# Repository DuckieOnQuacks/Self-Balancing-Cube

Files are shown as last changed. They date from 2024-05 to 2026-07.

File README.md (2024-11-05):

# Self-Balancing-Cube

**UPDATE (2024-07-14)**

New code is in **esp32_cube_enc** folder. I changed sensor orientation. So, if you make my cube before, to use this code, you need to reprint one part.

Or you can print redesigned cube https://www.thingiverse.com/thing:6695891

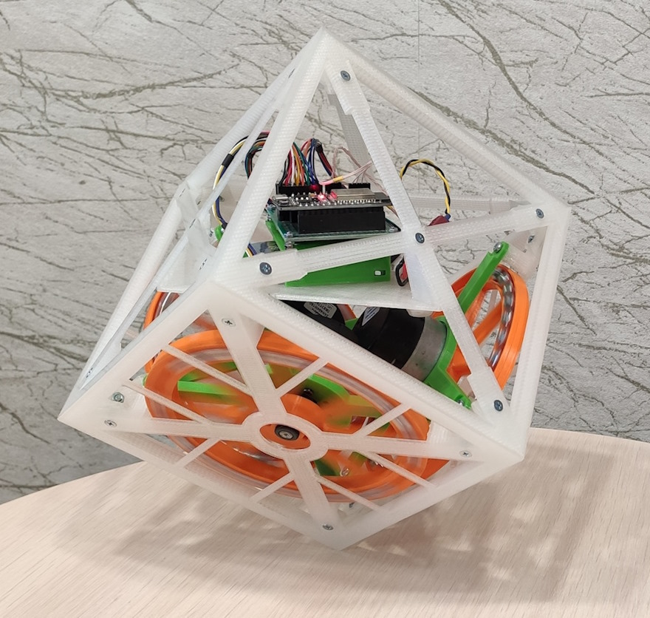
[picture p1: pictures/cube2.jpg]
Cubli


The red connections you see in the schematic must be connected!

If something doesn't work, try the motors test sketch. It tests all motors, rotation directions and encoders.

Folow this video https://youtu.be/ZU0oTBRDgOE

---

ESP32, MPU6050, Nidec 24H brushless motors, 500 mAh LiPo battery.

Balancing controllers can be tuned remotely over bluetooth.

Example:

Send p+ (or p+p+p+p+p+p+p+) for increase K1.

Send p- (or p-p-p-p-p-p-p-) for decrease K1.

The same for K2, K3. Send "i", "s".

Self-Balancing-Cube

Self-Balancing-Cube-Schematic

About schematic:

Battery: 3S1P LiPo (11.1V). 
Buzzer: any 5V active buzzer.
Voltage regulator: any 5V regulator (7805).
All red connections not nescesary for this project! But if you are designing a PCB I recommend making these connections. Maybe I use encoders in the future, you will be able to use the new firmware without any changes.
 
How to build:

https://youtu.be/AJQZFHJzwt4

If something doesn't work, try the motors test sketch. It tests all motors, rotation directions and speeds. This helps you understand the problem is in software or in hardware.

You can also make this balancing cube with Arduino nano controller. All other parts remain the same.

Self-Balancing-Cube-Schematic

In this version I make offsets setting procedure more simple. First connect to controller over bluetooth. 
You will see a message that you need to calibrate the balancing points. Send c+ from serial monitor. This activate calibrating procedure. 
Set the cube to one of balancing points (edge or vertex). Hold still when the cube does not fall to either side. Send c- from serial monitor. 
This will write the offsets to the EEPROM. Repeat this procedure four times (3 edges and vertex). After calibrating all offsets, the cube will begin to balance.

ESP32 version also has an updated balancing point setting procedure. Important! In this video you can learn how to set the balancing points:

https://youtu.be/Nkm9PoihZOI

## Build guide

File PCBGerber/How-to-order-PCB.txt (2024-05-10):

How to Order PCB

Please refer to:
https://docs.easyeda.com/en/PCB/Order-PCB

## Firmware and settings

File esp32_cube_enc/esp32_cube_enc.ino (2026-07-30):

#include "ESP32.h"
#include <Wire.h>
#include <EEPROM.h>
#include "BluetoothSerial.h"
#include <FastLED.h>

BluetoothSerial SerialBT;
CRGB leds[NUM_PIXELS];

void setup() {
  // ---- MOTOR SAFETY: this block must run before anything slow. ----
  // Until LEDC is attached, the PWM pins float, and this driver hardware
  // treats a floating/LOW PWM input as FULL DRIVE (the PWM is inverted:
  // 255 = stopped).  Engage the brake and force all three PWM outputs to
  // the stopped level immediately, so the motors cannot run away during
  // the LED animation and gyro-bias measurement below.
  pinMode(BRAKE, OUTPUT);
  digitalWrite(BRAKE, LOW);   // brake engaged; the balancing loop releases
                              // it only when an upright pose is active
  pinMode(DIR1, OUTPUT);
  pinMode(DIR2, OUTPUT);
  pinMode(DIR3, OUTPUT);
  // ESP32 core 3.x API: ledcAttach() replaces ledcSetup()+ledcAttachPin()
  // and manages the channel internally; PWM is now addressed by pin.
  bool pwm_ok = ledcAttach(PWM1, BASE_FREQ, TIMER_BIT);
  pwm_ok = ledcAttach(PWM2, BASE_FREQ, TIMER_BIT) && pwm_ok;
  pwm_ok = ledcAttach(PWM3, BASE_FREQ, TIMER_BIT) && pwm_ok;
  Motor1_control(0);          // duty 255 = stopped (inverted PWM)
  Motor2_control(0);
  Motor3_control(0);
  // ---- end motor safety block ----

  // Start the two serial interfaces: USB serial is useful for diagnostics,
  // while Bluetooth is used to tune gains and run calibration.
  Serial.begin(115200);
  // If any LEDC attach failed, the PWM pins are still floating and the
  // motors are NOT safe: report it loudly and keep the brake engaged.
  if (!pwm_ok)
    Serial.println("ERROR: motor PWM attach failed - outputs unconfigured!");
  SerialBT.begin("ESP32-Cube"); // Bluetooth device name
  EEPROM.begin(EEPROM_SIZE);

  // The three WS2812B LEDs provide visual feedback during startup,
  // calibration, and low-battery warnings.
  FastLED.addLeds<WS2812B, LED_PIN, RGB>(leds, NUM_PIXELS);  // GRB ordering is typical

  pinMode(BUZZER, OUTPUT);

  // Cycle through red, green, and blue to show that the LEDs are working.
  for (int i=0;i<=255;i+=10) {
    leds[0] = CRGB(i, 0, 0);
    leds[1] = CRGB(i, 0, 0);
    leds[2] = CRGB(i, 0, 0);
    FastLED.show();
    delay(5);
  }
  delay(300);
  for (int i=0;i<=255;i+=10) {
    leds[0] = CRGB(0, i, 0);
    leds[1] = CRGB(0, i, 0);
    leds[2] = CRGB(0, i, 0);
    FastLED.show();
    delay(5);
  }
  delay(300);
  for (int i=0;i<=255;i+=10) {
    leds[0] = CRGB(0, 0, i);
    leds[1] = CRGB(0, 0, i);
    leds[2] = CRGB(0, 0, i);
    FastLED.show();
    delay(5);
  }
  delay(300);
  leds[0] = CRGB::Black;
  leds[1] = CRGB::Black;
  leds[2] = CRGB::Black;
  FastLED.show();
  
  // Encoder inputs: both channels of each encoder trigger the same
  // quadrature decoder on every edge.  (Direction/PWM outputs were already
  // configured in the motor-safety block at the top of setup().)
  pinMode(ENC1_1, INPUT);
  pinMode(ENC1_2, INPUT);
  attachInterrupt(ENC1_1, ENC1_READ, CHANGE);
  attachInterrupt(ENC1_2, ENC1_READ, CHANGE);

  pinMode(ENC2_1, INPUT);
  pinMode(ENC2_2, INPUT);
  attachInterrupt(ENC2_1, ENC2_READ, CHANGE);
  attachInterrupt(ENC2_2, ENC2_READ, CHANGE);

  pinMode(ENC3_1, INPUT);
  pinMode(ENC3_2, INPUT);
  attachInterrupt(ENC3_1, ENC3_READ, CHANGE);
  attachInterrupt(ENC3_2, ENC3_READ, CHANGE);

  // A valid ID means that accelerometer offsets were previously saved.
  // EEPROM data survives power cycles, so calibration is normally needed only
  // after changing the hardware or clearing the EEPROM.
  EEPROM.get(0, offsets);
  if (offsets.ID == 96) 
    calibrated = true;

  delay(200);
  // Configure the MPU6050 and measure the gyro's stationary bias.
  angle_setup();

  // Start the Wi-Fi access point and web server (see web_interface.ino).
  // Done last so it cannot disturb the gyro-bias measurement above.
  startWebInterface();
}

void loop() {
  currentT = millis();
  // This is the fast control loop.  It is deliberately time-based rather
  // than delay-based so sensor and motor work can run at a stable period.
  if (currentT - previousT_1 >= loop_time) {
    Tuning();
    angle_calc();

    // Encoder interrupts accumulate counts between control-loop iterations.
    // Copy each interval's count as a speed estimate, then start a new one.
    motor1_speed = enc_count1;
    enc_count1 = 0;
    motor2_speed = enc_count2;
    enc_count2 = 0;
    motor3_speed = enc_count3;
    enc_count3 = 0;
    // Convert the three motor speeds into the cube's X/Y motion components.
    threeWay_to_XY(motor1_speed, motor2_speed, motor3_speed);
    motors_speed_Z = motor1_speed + motor2_speed + motor3_speed;
    
    // Vertex mode controls two tilt axes and the common Z rotation axis.
    if (vertical_vertex && calibrated && !calibrating) {    
      digitalWrite(BRAKE, HIGH);
      gyroX = GyX / 131.0;
      gyroY = GyY / 131.0;
      gyroZ = GyZ / 131.0;
      gyroXfilt = alpha * gyroX + (1 - alpha) * gyroXfilt;
      gyroYfilt = alpha * gyroY + (1 - alpha) * gyroYfilt;
      
      // Each term counters a different part of the motion:
      // angle keeps the cube upright, gyro rate damps it, and the speed terms
      // reduce motion that would otherwise build up around the equilibrium.
      int pwm_X = constrain(K1 * robot_angleX + K2 * gyroXfilt + K3 * speed_X + K4 * motors_speed_X, -255, 255);
      int pwm_Y = constrain(K1 * robot_angleY + K2 * gyroYfilt + K3 * speed_Y + K4 * motors_speed_Y, -255, 255);
      int pwm_Z = constrain(zK2 * gyroZ + zK3 * motors_speed_Z, -255, 255);

      // A small accumulated speed correction acts like an integral term.
      motors_speed_X += speed_X / 5; 
      motors_speed_Y += speed_Y / 5;
      // Transform desired X/Y/Z forces into the three motor commands.
      XYZ_to_threeWay(-pwm_X, pwm_Y, -pwm_Z);
    } else if (vertical_edge && calibrated && !calibrating) {
      // In edge mode, only motor 3 is used to correct the detected tilt.
      digitalWrite(BRAKE, HIGH);
      gyroX = GyX / 131.0;
      gyroXfilt = alpha * gyroX + (1 - alpha) * gyroXfilt;
      
      int pwm_X = constrain(eK1 * robot_angleX + eK2 * gyroXfilt + eK3 * motor3_speed + eK4 * motors_speed_X, -255, 255);
      
      motors_speed_X += motor3_speed / 5;
      Motor3_control(pwm_X);
    } else {
      // If the cube is not in a recognized balancing pose, stop applying
      // drive and engage the brake.  This protects the motors during setup or
      // after the cube has fallen.
      XYZ_to_threeWay(0, 0, 0);
      digitalWrite(BRAKE, LOW);
      motors_speed_X = 0;
      motors_speed_Y = 0;
    }
    previousT_1 = currentT;
  }
  
  // Slow status loop: check battery voltage and blink LEDs until calibration
  // has been completed.
  if (currentT - previousT_2 >= 2000) {    
    battVoltage((double)analogRead(VBAT) / 204); // value 204 must be selected by measuring battery voltage!
    if (!calibrated && !calibrating) {
      SerialBT.println("first you need to calibrate the balancing points...");
      Serial.println("first you need to calibrate the balancing points (over bluetooth)...");
      if (!calibrated_leds) {
        leds[0] = CRGB(0, 255, 0);
        leds[1] = CRGB(0, 255, 0);
        leds[2] = CRGB(0, 255, 0);
        FastLED.show();
        calibrated_leds = true; 
      } else {
        leds[0] = CRGB::Black;
        leds[1] = CRGB::Black;
        leds[2] = CRGB::Black;
        FastLED.show();
        calibrated_leds = false; 
      }
    }
    previousT_2 = currentT;
  }

  // Service pending HTTP clients (web_interface.ino).  Non-blocking: it
  // returns immediately when no client is connected, so the timed balancing
  // loop above is unaffected.
  handleWebInterface();
}

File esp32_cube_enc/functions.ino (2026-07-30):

void writeTo(byte device, byte address, byte value) {
  // Helper for writing one byte to an MPU6050 register over I2C.
  Wire.beginTransmission(device);
  Wire.write(address);
  Wire.write(value);
  Wire.endTransmission(true);
}

void beep() {
    // The active buzzer sounds while its pin is HIGH.
    digitalWrite(BUZZER, HIGH);
    delay(70);
    digitalWrite(BUZZER, LOW);
    delay(80);
}

void save() {
    // ESP32 EEPROM emulation needs commit() to persist the new calibration.
    EEPROM.put(0, offsets);
    EEPROM.commit();
    EEPROM.get(0, offsets);
    if (offsets.ID == 96) calibrated = true;
    calibrating = false;
    SerialBT.println("Calibrating off.");
    beep();
}

void angle_setup() {
  // Wake the MPU6050 and select the measurement ranges from ESP32.h.
  Wire.begin();
  delay (100);
  writeTo(MPU6050, PWR_MGMT_1, 0);
  writeTo(MPU6050, ACCEL_CONFIG, accSens << 3); // Specifying output scaling of accelerometer
  writeTo(MPU6050, GYRO_CONFIG, gyroSens << 3); // Specifying output scaling of gyroscope
  delay (100);
  
  // Average 512 stationary samples on each gyro axis to measure its bias.
  beep();
  leds[2] = CRGB(0, 0, 200);
  FastLED.show();
  for (int i = 0; i < 512; i++) {
    angle_calc();
    GyZ_offset_sum += GyZ;
    delay(5);
  }
  GyZ_offset = GyZ_offset_sum >> 9;
  Serial.print("GyZ offset value = "); Serial.println(GyZ_offset);
  beep();
  leds[2] = CRGB::Black;
  FastLED.show();

  leds[1] = CRGB(0, 0, 200);
  FastLED.show();
  for (int i = 0; i < 512; i++) {
    angle_calc();
    GyY_offset_sum += GyY;
    delay(5);
  }
  GyY_offset = GyY_offset_sum >> 9;
  Serial.print("GyY offset value = "); Serial.println(GyY_offset);
  beep();
  leds[1] = CRGB::Black;
  FastLED.show();

  leds[0] = CRGB(0, 0, 200);
  FastLED.show();
  for (int i = 0; i < 512; i++) {
    angle_calc();
    GyX_offset_sum += GyX;
    delay(5);
  }
  GyX_offset = GyX_offset_sum >> 9;
  Serial.print("GyX offset value = "); Serial.println(GyX_offset);
  beep();
  beep();
  leds[0] = CRGB::Black;
  FastLED.show();

  leds[0] = CRGB(255, 0, 0);
  leds[1] = CRGB(255, 0, 0);
  leds[2] = CRGB(255, 0, 0);
  FastLED.show();
  delay(300);
  leds[0] = CRGB::Black;
  leds[1] = CRGB::Black;
  leds[2] = CRGB::Black;
  FastLED.show();
  delay(150);
  leds[0] = CRGB(255, 0, 0);
  leds[1] = CRGB(255, 0, 0);
  leds[2] = CRGB(255, 0, 0);
  FastLED.show();
  delay(300);
  leds[0] = CRGB::Black;
  leds[1] = CRGB::Black;
  leds[2] = CRGB::Black;
  FastLED.show();
  delay(300);
}

void angle_calc() {
  // Read the three raw gyro registers (0x43 through 0x48).
  Wire.beginTransmission(MPU6050);
  Wire.write(0x43);
  Wire.endTransmission(false);
  Wire.requestFrom(MPU6050, 6, true);  
  GyX = Wire.read() << 8 | Wire.read();
  GyY = Wire.read() << 8 | Wire.read();
  GyZ = Wire.read() << 8 | Wire.read();

  // Read the three raw accelerometer registers (0x3B through 0x40).
  Wire.beginTransmission(MPU6050);
  Wire.write(0x3B);                  
  Wire.endTransmission(false);
  Wire.requestFrom(MPU6050, 6, true); 
  AcX = Wire.read() << 8 | Wire.read();
  AcY = Wire.read() << 8 | Wire.read();
  AcZ = Wire.read() << 8 | Wire.read();

  // Use the calibration values for the currently detected pose: small |AcX|
  // means vertex mode, while a larger |AcX| means edge mode.
  if (abs(AcX) < 2000) {
    AcXc = AcX - offsets.acXv;
    AcYc = AcY - offsets.acYv;
    AcZc = AcZ - offsets.acZv;
  } else {
    AcXc = AcX - offsets.acXe;
    AcYc = AcY - offsets.acYe;
    AcZc = AcZ - offsets.acZe;
  }
  // Remove the stationary gyro bias before integrating angular velocity.
  GyZ -= GyZ_offset;
  GyY -= GyY_offset;
  GyX -= GyX_offset;

  // Integrate gyro rate into an angle.  65.536 converts raw readings at the
  // selected ±250°/s gyro range into degrees per second.
  robot_angleY += GyY * loop_time / 1000 / 65.536;
  Acc_angleY = atan2(AcXc, -AcZc) * 57.2958;
  // Combine fast gyro response with the accelerometer's long-term reference.
  robot_angleY = robot_angleY * Gyro_amount + Acc_angleY * (1.0 - Gyro_amount);

  robot_angleX += GyX * loop_time / 1000 / 65.536;
  Acc_angleX = -atan2(AcYc, -AcZc) * 57.2958;
  robot_angleX = robot_angleX * Gyro_amount + Acc_angleX * (1.0 - Gyro_amount);

  // Recognize a stable upright vertex or edge.  The tight angle thresholds
  // prevent balancing from starting while the cube is being placed.
  if (abs(AcX) < 2000 && abs(Acc_angleX) < 0.4 && abs(Acc_angleY) < 0.4 && !vertical_vertex && !vertical_edge) {
    robot_angleX = Acc_angleX;
    robot_angleY = Acc_angleY;
    vertical_vertex = true;
  } else if (abs(AcX) > 7000 && abs(AcX) < 10000 && abs(Acc_angleX) < 0.3 && !vertical_vertex && !vertical_edge) {
    robot_angleX = Acc_angleX;
    robot_angleY = Acc_angleY;
    vertical_edge = true;
  // Leaving the upright range disables the active balancing mode.
  } else if ((abs(robot_angleX) > 7 || abs(robot_angleY) > 7) && vertical_vertex) {
    vertical_vertex = false;
  } else if ((abs(robot_angleX) > 7 || abs(robot_angleY) > 7) && vertical_edge) {
    vertical_edge = false;
  }
}

void XYZ_to_threeWay(float pwm_X, float pwm_Y, float pwm_Z) {
  // The three motors are arranged 120° apart.  Convert desired X/Y/Z axis
  // commands into individual motor commands using the inverse mix.
  // 0.5 and 0.866 are cos(60°) and sin(60°); the other factors compensate
  // for this hardware's motor geometry and scale.
  int16_t m1 = round((0.5 * pwm_X - 0.866 * pwm_Y) / 1.37 + pwm_Z);  
  int16_t m2 = round((0.5 * pwm_X + 0.866 * pwm_Y) / 1.37 + pwm_Z);
  int16_t m3 = -pwm_X / 1.37 + pwm_Z;  
  Motor1_control(m1);
  Motor2_control(m2);
  Motor3_control(m3);
}

void threeWay_to_XY(int in_speed1, int in_speed2, int in_speed3) {
  // Forward mix: reconstruct X/Y movement from measured motor speeds.
  speed_X = ((in_speed3 - (in_speed2 + in_speed1) * 0.5) * 0.5) * 1.81;
  speed_Y = -(-0.866 * (in_speed2 - in_speed1)) / 1.1;
}

void battVoltage(double voltage) {
  // voltage is the ADC value divided by a board-specific scale factor.  The
  // buzzer warns while the battery reading is in the configured low range.
  batt_voltage = voltage;   // keep a copy for the web interface (/api/state)
  if (voltage > 8 && voltage <= 9.5) {
    digitalWrite(BUZZER, HIGH);
  } else {
    digitalWrite(BUZZER, LOW);
  }
}

void pwmSet(uint8_t pin, uint32_t value) {
  // Write an 8-bit duty-cycle value to a PWM output.  ESP32 core 3.x
  // addresses LEDC by pin number (the old API used channel numbers).
  ledcWrite(pin, value);
}

void Motor1_control(int sp) {
  // Add the measured speed so the command includes motor-speed feedback.
  sp = sp + motor1_speed;
  if (sp < 0) 
    digitalWrite(DIR1, LOW);
  else 
    digitalWrite(DIR1, HIGH);
  // The driver uses inverted PWM: 255 is stopped and smaller values drive
  // the motor harder.
  pwmSet(PWM1, 255 - abs(sp));
}
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

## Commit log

2024-05-10 Added PCB Gerber Files
    [Drill_PTH_Through.DRL, Drill_PTH_Through_Via.DRL, Gerber_BoardOutlineLayer.GKO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]
2026-07-29 Refactor ESP32 encoder firmware and remove legacy
    Remove old Arduino/ESP32 sketches and schematics (ESP32_cube/, arduino_cube/, arduino_schematic.pdf, pictures/arduino_schematic.png). Substantially refactor esp32_cube_enc: centralize pin map and con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
2026-07-30 Add Wi-Fi web UI and motor-safety startup
    Add a non-blocking Wi‑Fi web interface (web_interface.ino) that starts an AP, registers a simple GET / handler, and exposes startWebInterface()/handleWebInterface() hooks called from setup()/loop(). Implement a motor-safety startup block in setup(): engage brake, initialize direction pins, attach LEDC PWM by pin (ESP32 core 3.x API), force motors to stopped duty, and report attach failures. Update pwmSet() to accept pins (not channels) and change Motor*_control() to use PWM pin writes. Reorder encoder attach/config so safety runs before any slow operations.
    [esp32_cube_enc.ino, functions.ino, web_interface.ino]
2026-07-30 Add /api/state endpoint and battery voltage
    Expose runtime telemetry via a new GET /api/state JSON endpoint and persist battery voltage for reporting. Introduces batt_voltage, updated in battVoltage(), and a handleApiState() handler that emits a bounded JSON snapshot (no heap String use). Also adds Wi‑Fi AP startup error checking and a helpful Serial message if softAP() fails (commonly due to short WPA2 passwords).
    [ESP32.h, functions.ino, web_interface.ino]
2026-07-30 Add PlatformIO config and IDE files
    Add project configuration and editor recommendations: create .gitignore (ignore .pio and VSCode DB/ipch files), .vscode/extensions.json (recommend PlatformIO IDE, mark cpptools pack unwanted), and pl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
